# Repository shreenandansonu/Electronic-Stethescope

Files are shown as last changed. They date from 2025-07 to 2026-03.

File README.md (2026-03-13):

    

 

# **EKOBIT** | Electronics Stethoscope

This project aims at making an affordable yet powerful **electronics stethoscope** to **record and listen** to the Heart and Lungs Sound. The stethoscope would be primarily used for teaching purposes for medical students at CMC Vellore, Bagayam Campus, Vellore, Tamil Nadu India. Below mentioned are the objective.

---
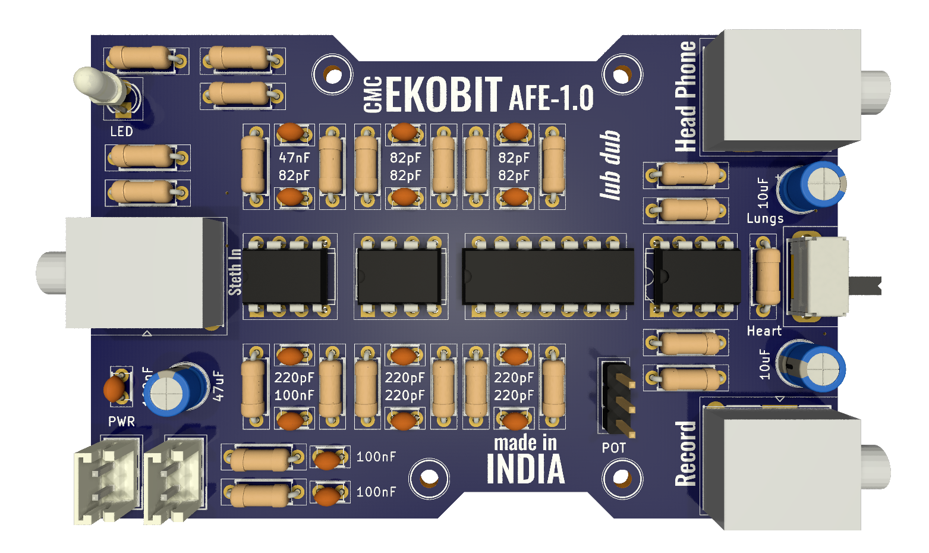
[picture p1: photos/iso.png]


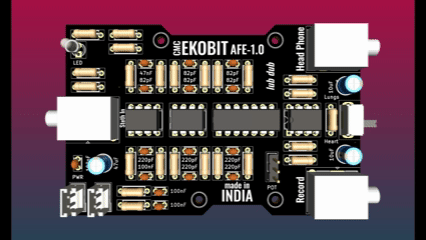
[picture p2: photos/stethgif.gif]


### **OBJECTIVE**
---
| Objectives | Status |
| :---: | :---: |
| Connect stethoscope to a microphone to capture sounds. |  |
| Amplify heart and lung sounds using custom circuits. |   |
| Filter captured sounds using built electronic circuits. |   |
| Transfer audio to PC/mobile via 3.5 mm jack. |   |
| Record and save audio using open-source/custom software. |   |

```
Digitial Version of this device is in progress........
```

## **DEMO**
[EKOBIT DEMO VIDEO](https://youtu.be/8x4jnvdGgfg?si=aJdlGi542GCe0jYr)
---

## **SOFTWARE**
[SOFTWARE DOWNLOAD](https://cmcekobit.netlify.app/)
---

## **DOCUMENTATION**
[DOCUMENTATION DOWNLOAD](https://cmcekobit.netlify.app/EKOBIT.pdf)
---

| Top View | Bottom View |
| :---: | :---: |
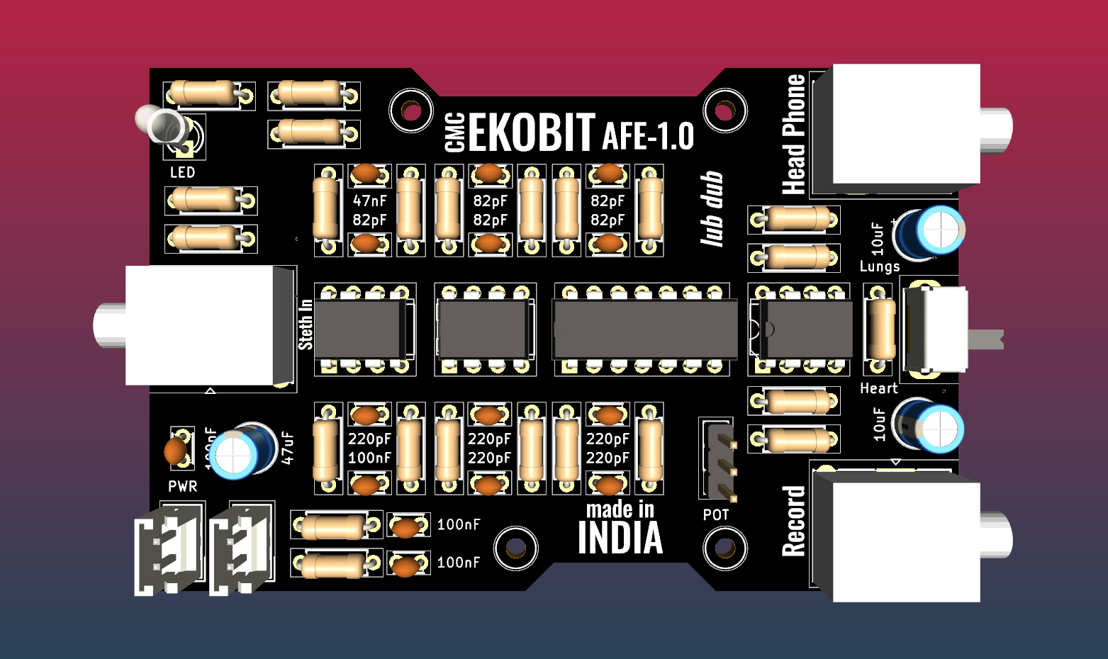
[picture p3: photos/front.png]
Front View
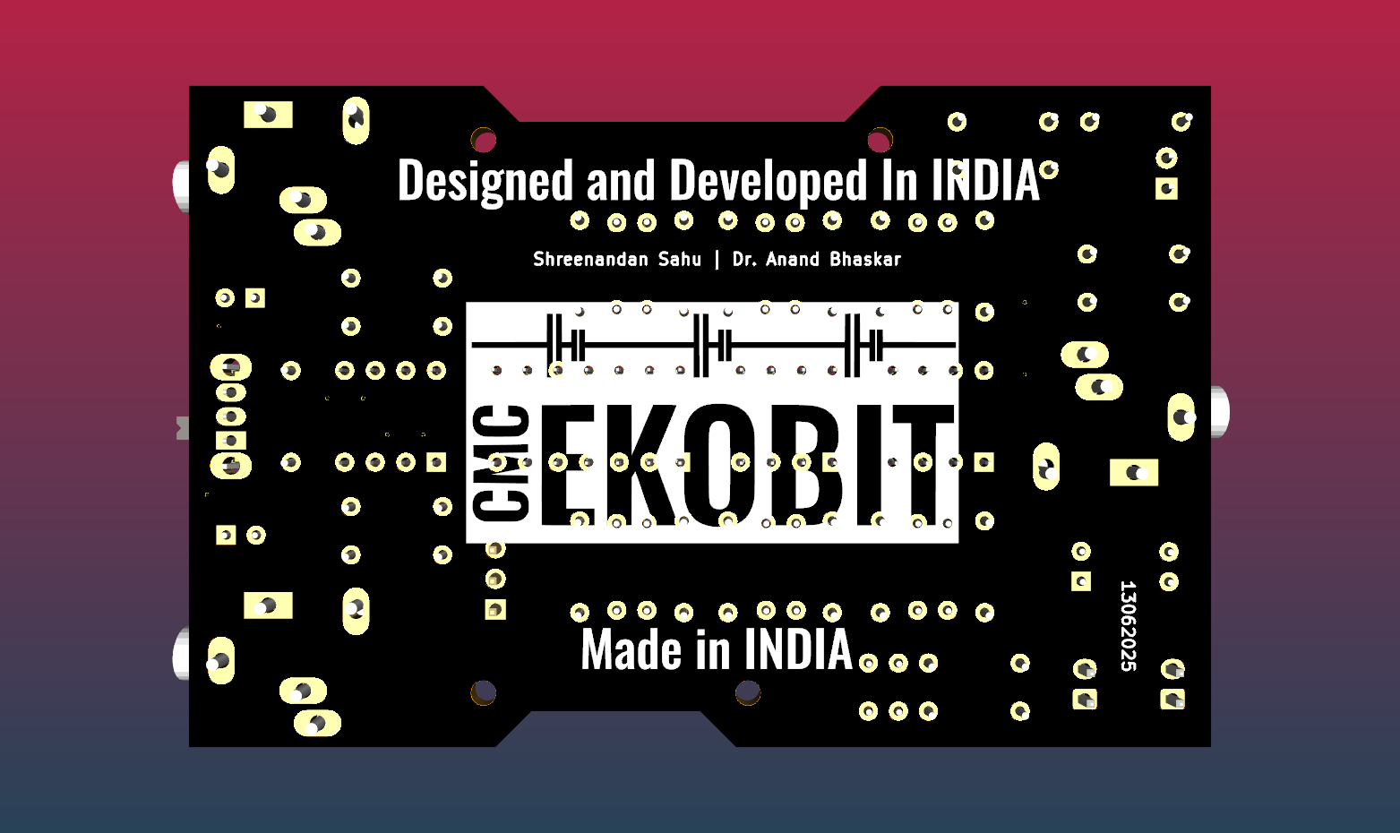
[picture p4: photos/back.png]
Bottom View
|   |   |

---
| PCB Layout | Schematics |
| :---: | :---: |
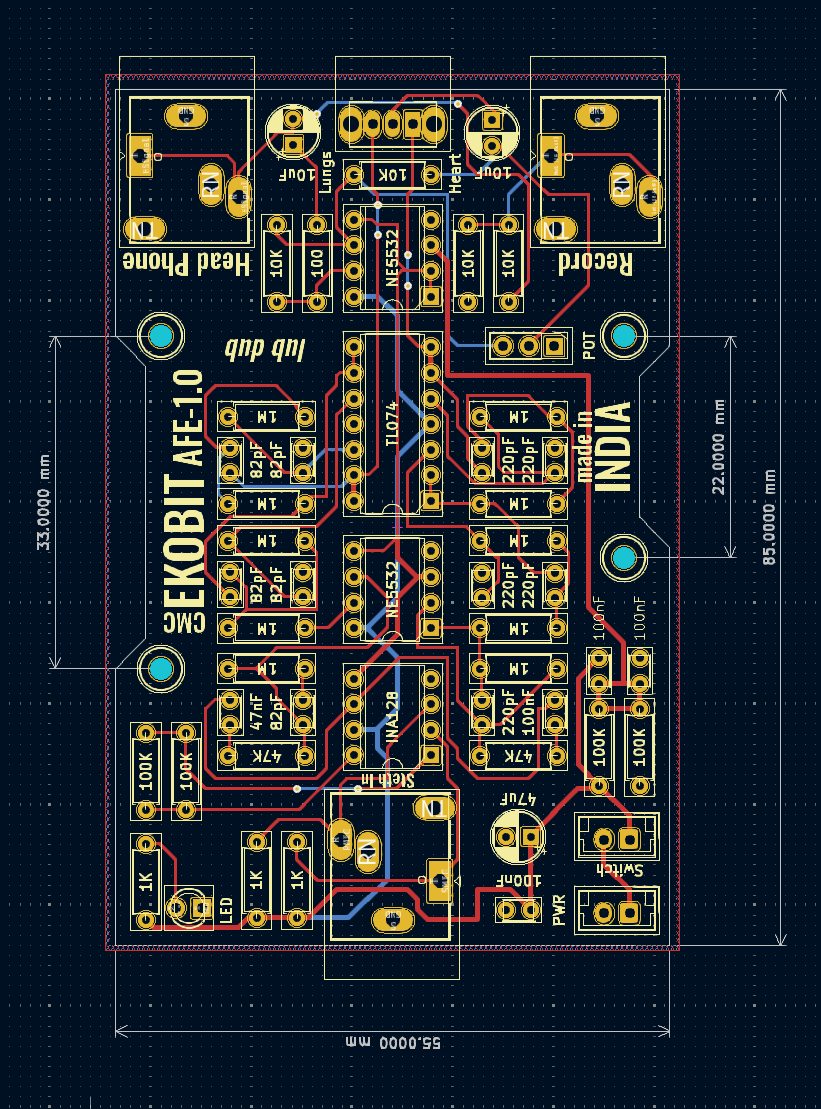
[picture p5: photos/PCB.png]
PCB View
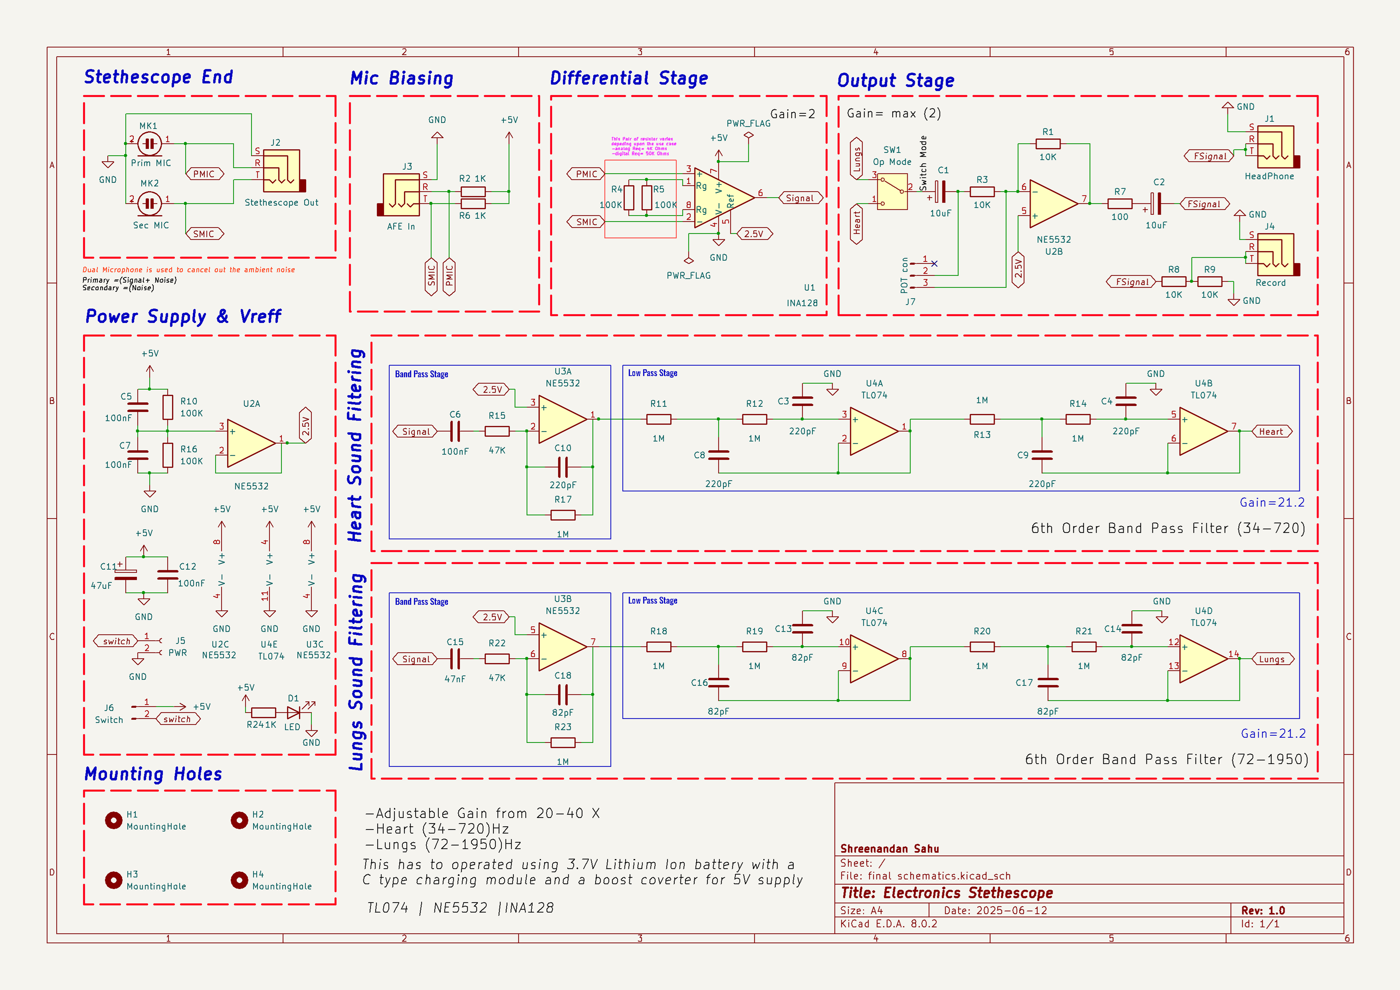
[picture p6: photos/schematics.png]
Schematics
|   |  |

---
| Stethoscope Connector | Stethoscope Enclouser |
| :---: | :---: |
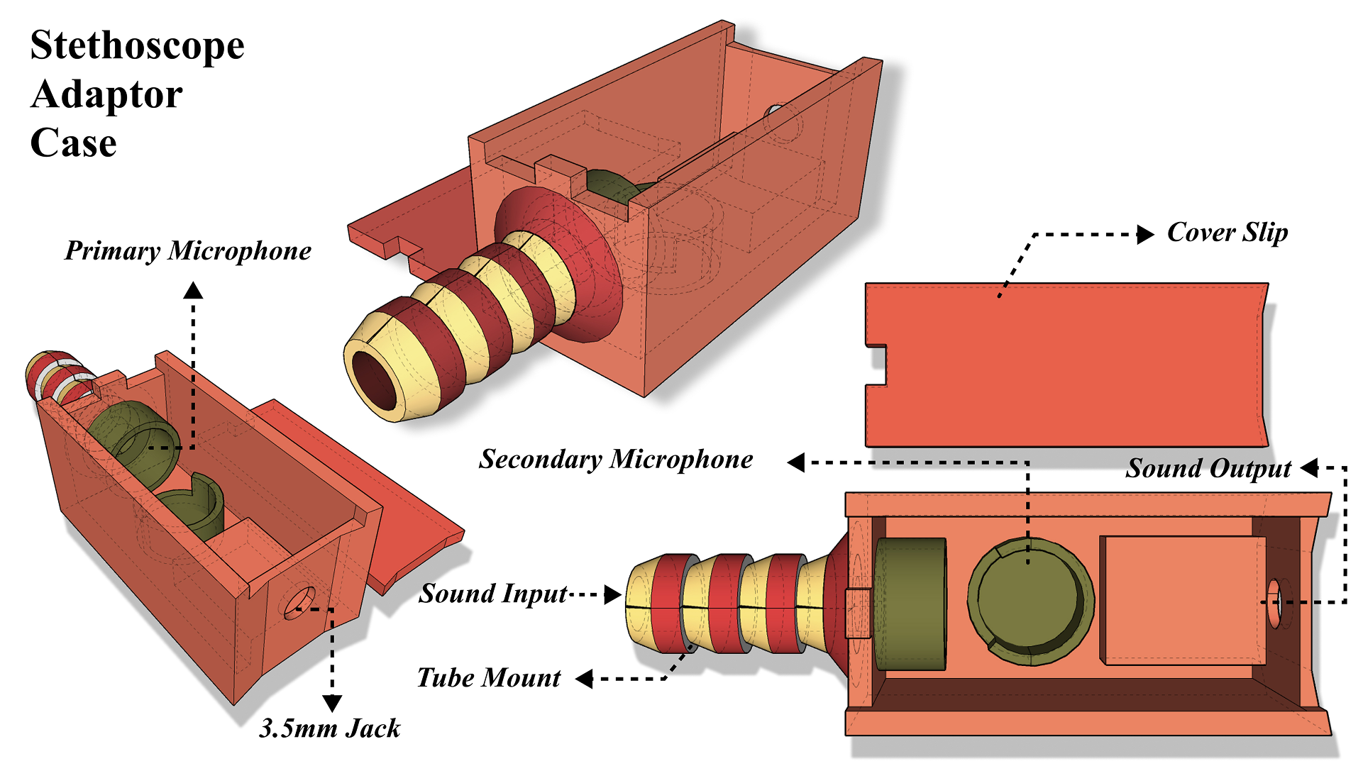
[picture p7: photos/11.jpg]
EKOBIT Stethoconn
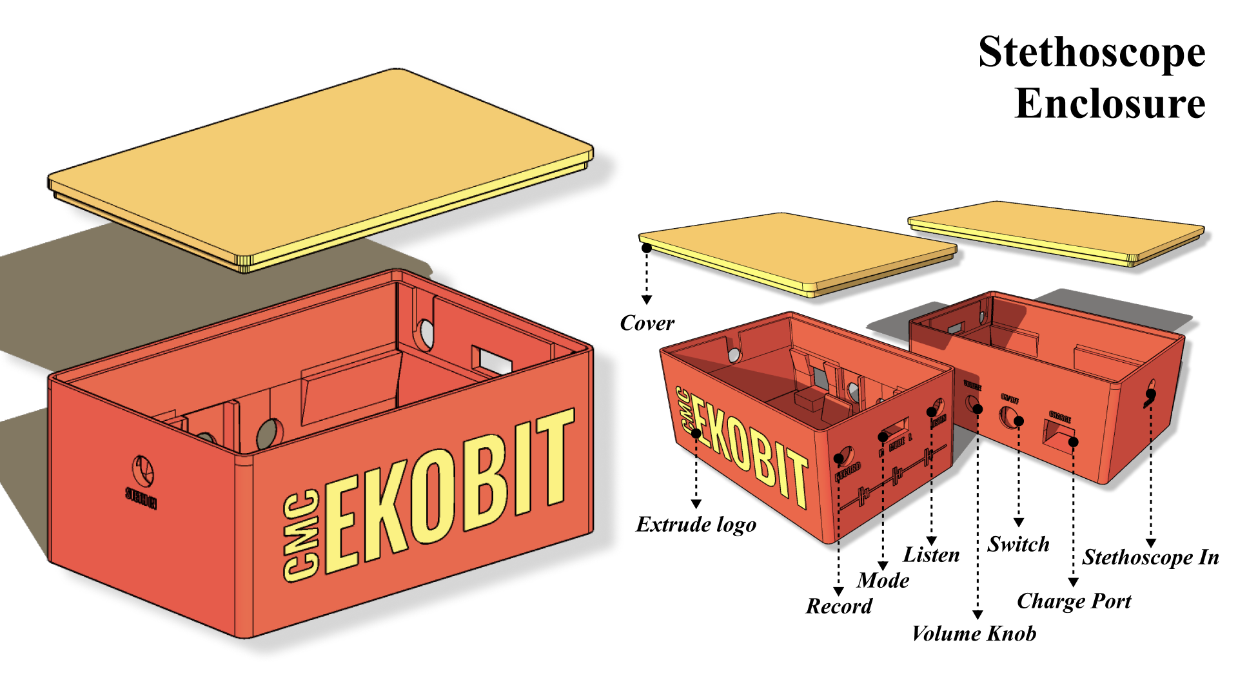
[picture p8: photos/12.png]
EKOBIT enclouser
|   |  |

### **RAW VS PROCESSED** signal DSO

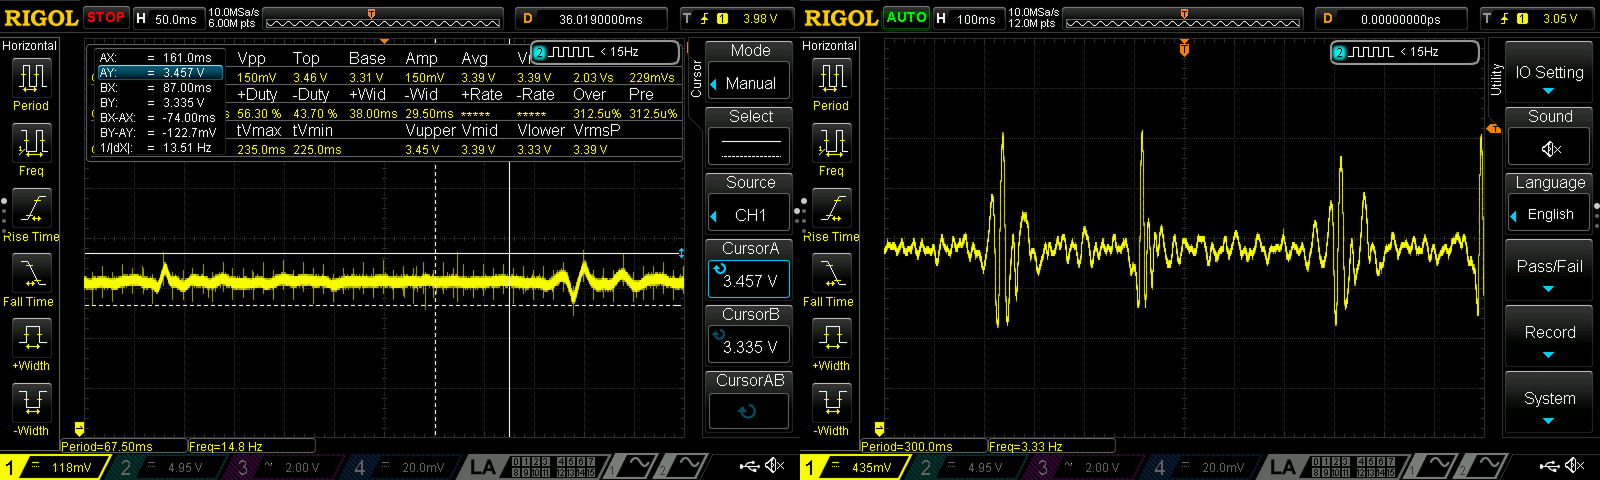
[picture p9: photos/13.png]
DSO Compare


### **RECORDING SOFTWARE**

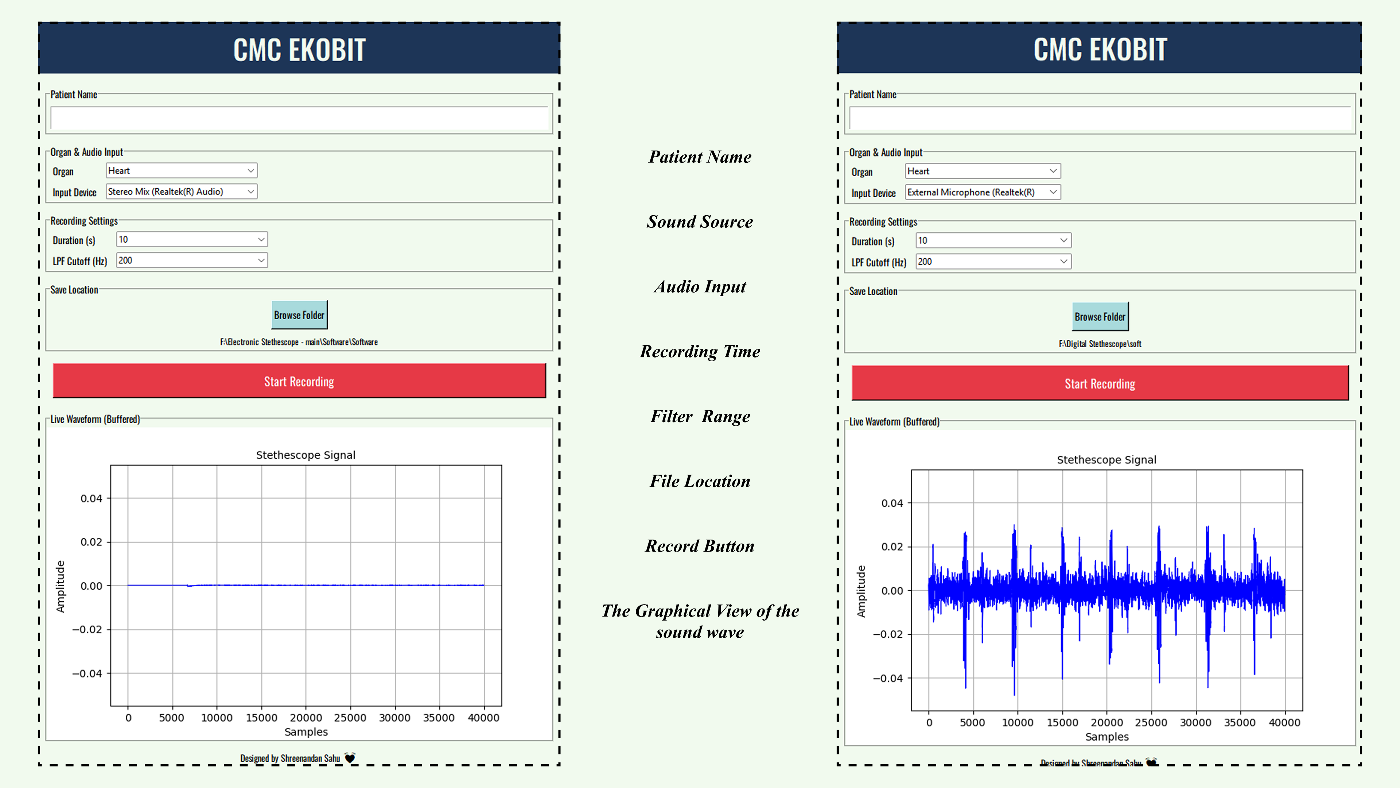
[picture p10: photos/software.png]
Software Anatomy


### **SPECTOGRAM OF RECORDED SOUND**

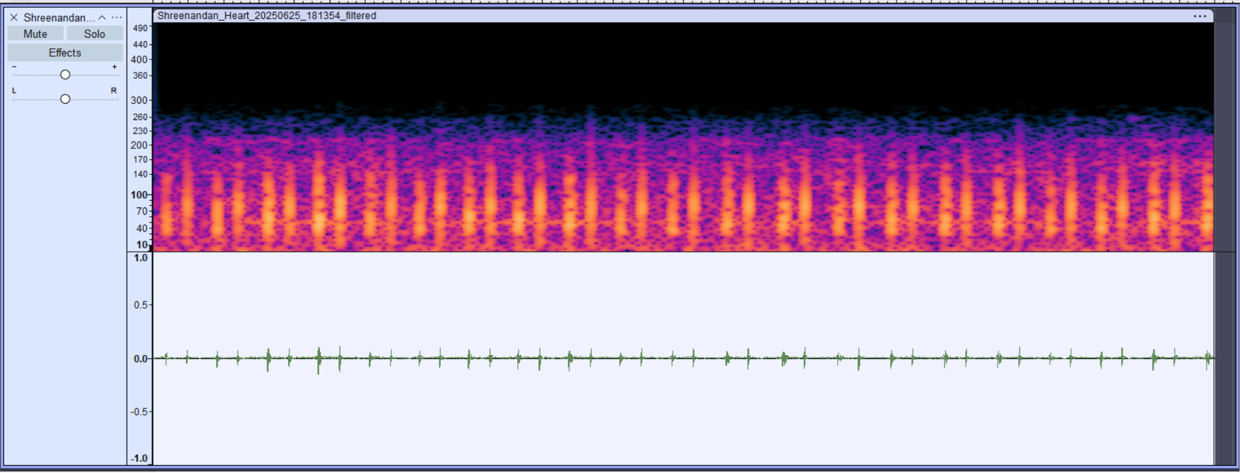
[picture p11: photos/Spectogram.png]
Spectrogram


---
### **FINAL DEVICE DEVELOPED**
| **FINAL PRODUCT** | **HARDWARE** |
| :---: | :---: |
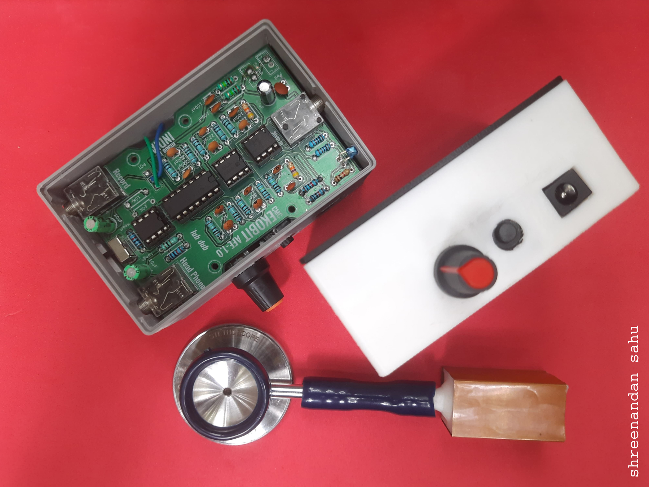
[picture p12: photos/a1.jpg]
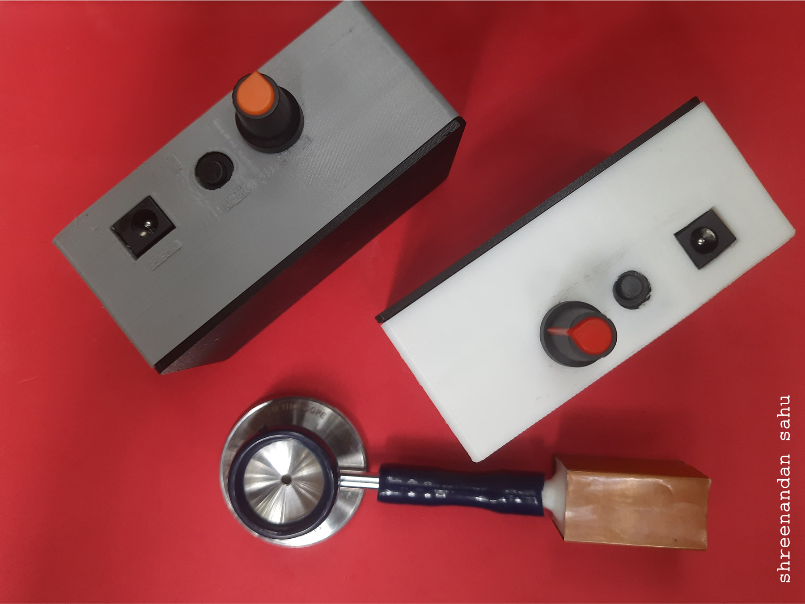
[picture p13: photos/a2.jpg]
| |  |
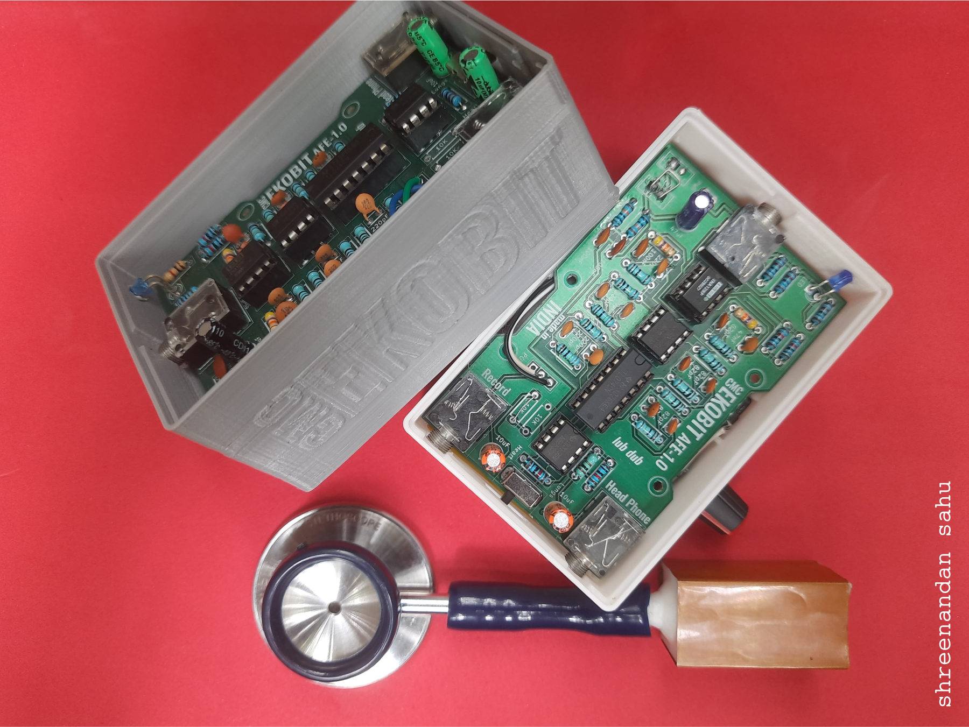
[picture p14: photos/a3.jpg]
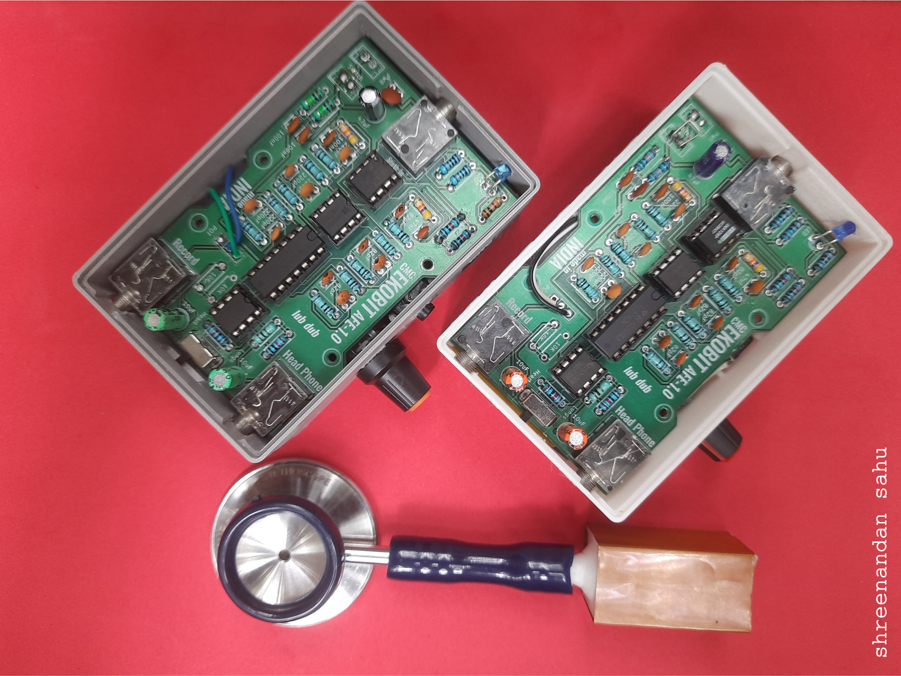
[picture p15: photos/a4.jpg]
| |  |
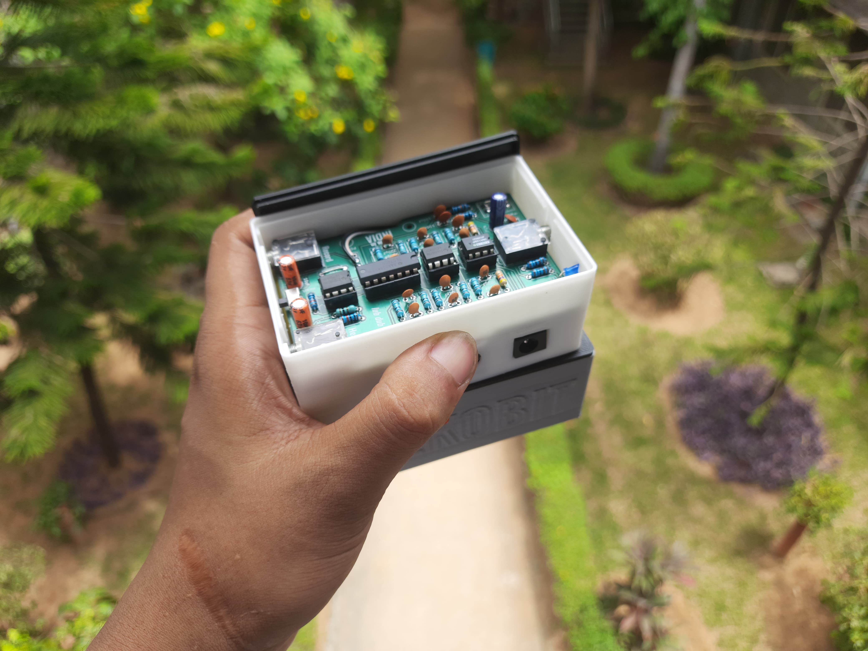
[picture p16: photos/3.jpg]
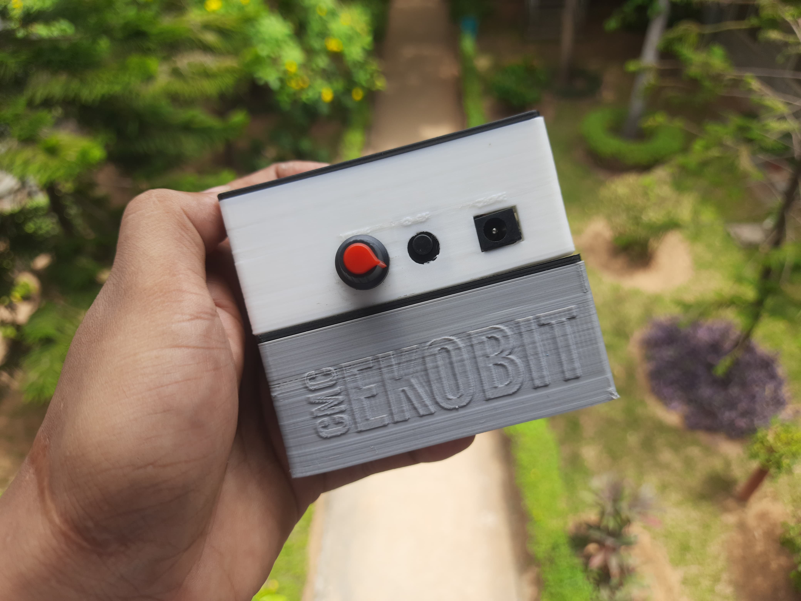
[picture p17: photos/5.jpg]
| |  |
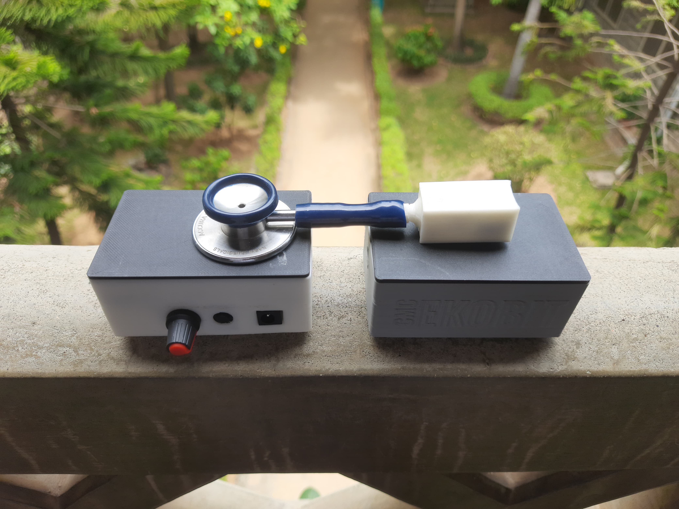
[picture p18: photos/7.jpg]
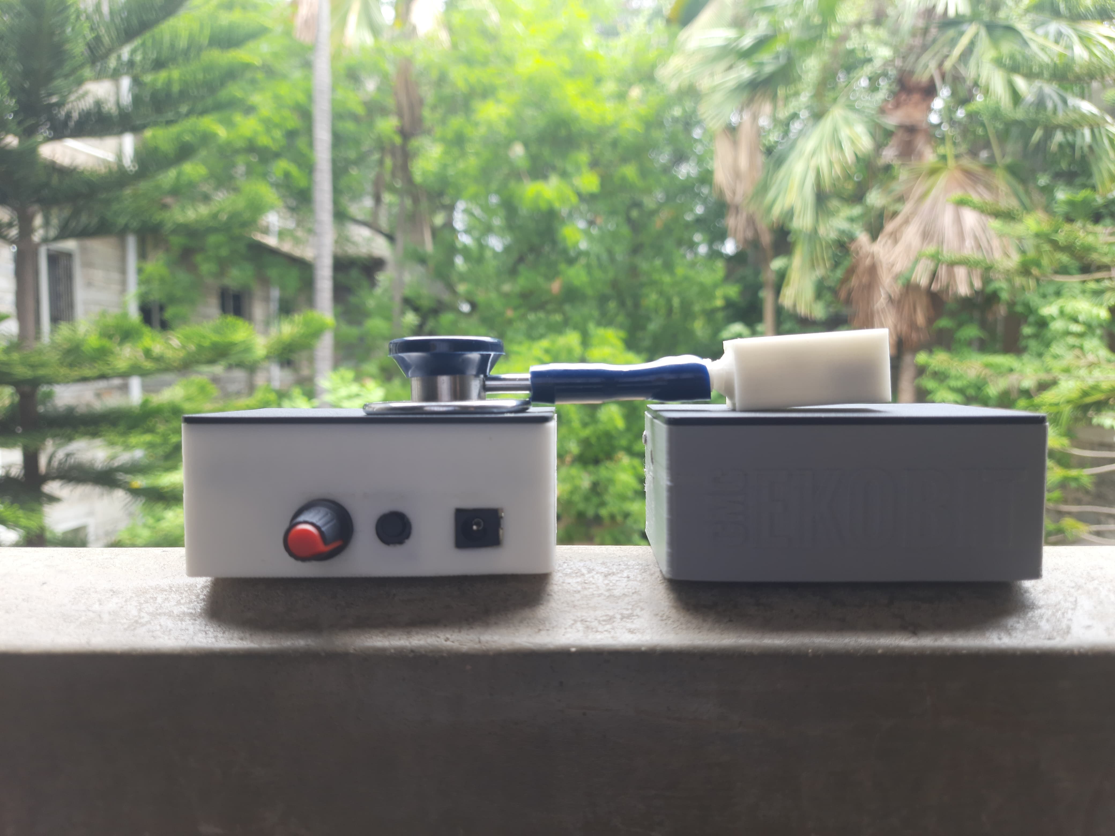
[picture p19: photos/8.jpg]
| |  |

---
### **BEHIND THE DEVELOPMENT**
| **PRODUCT DEVELOPMENT** | **PROTOTYPING** |
| :---: | :---: |
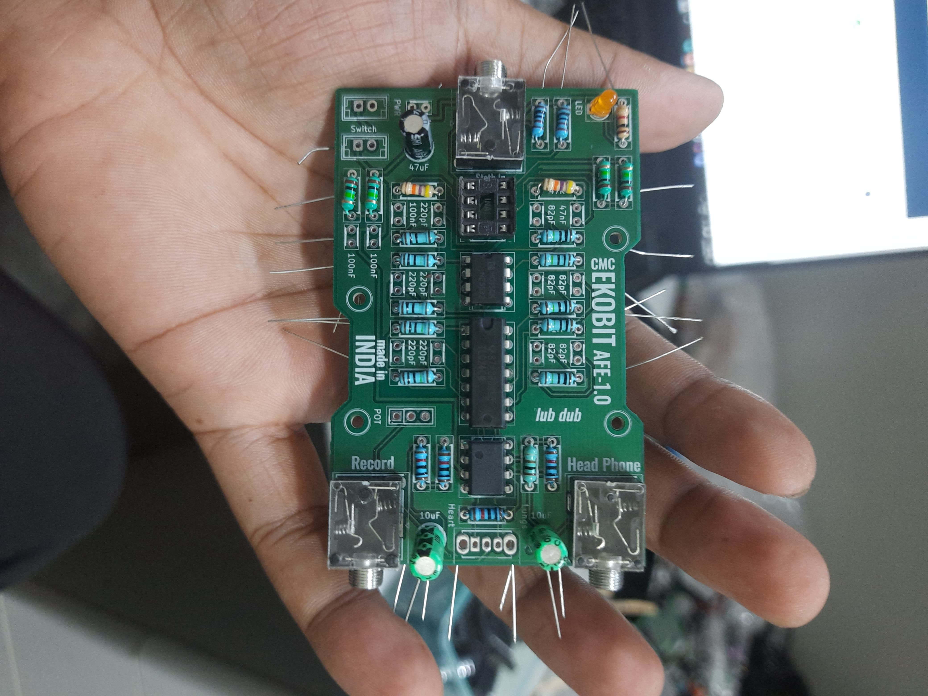
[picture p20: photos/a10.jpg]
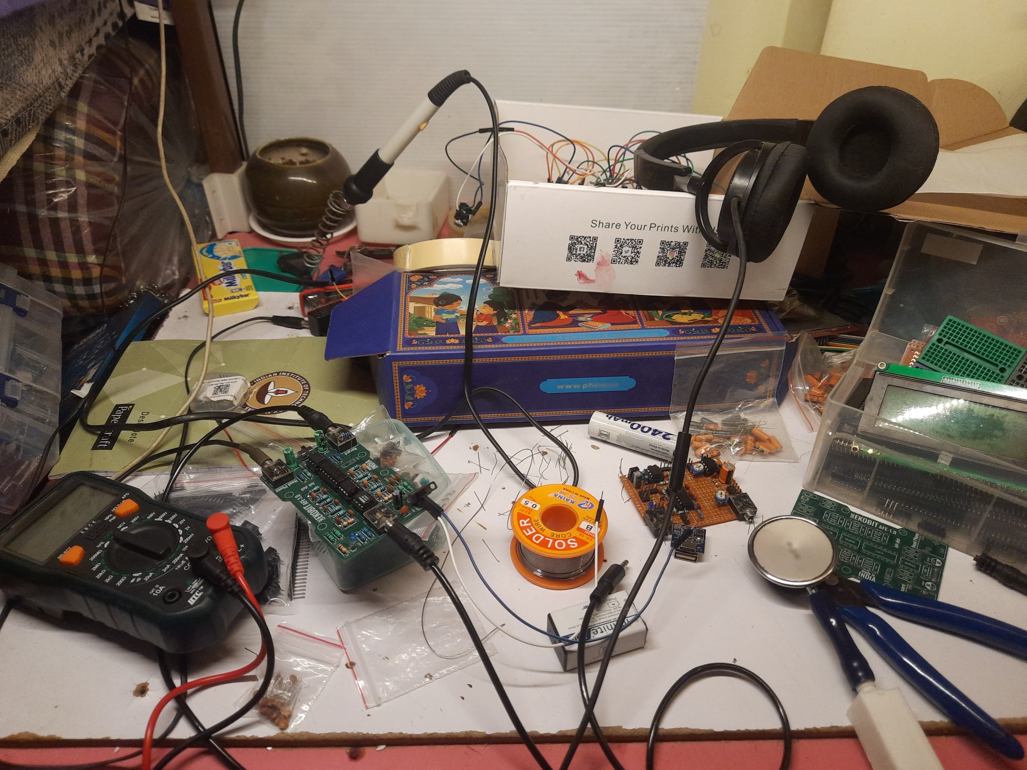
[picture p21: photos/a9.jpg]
| |  |
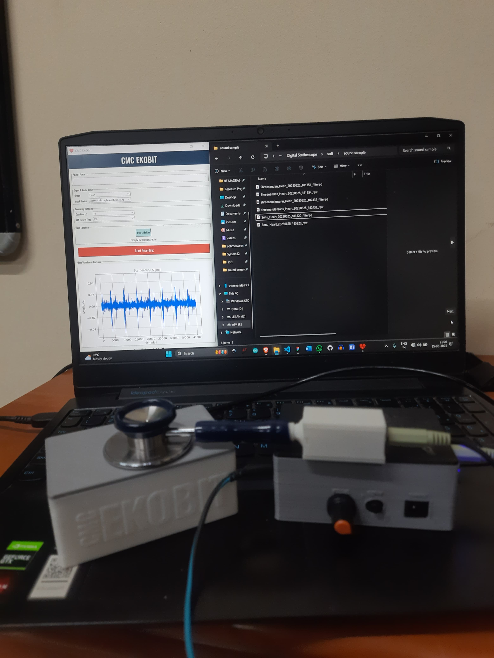
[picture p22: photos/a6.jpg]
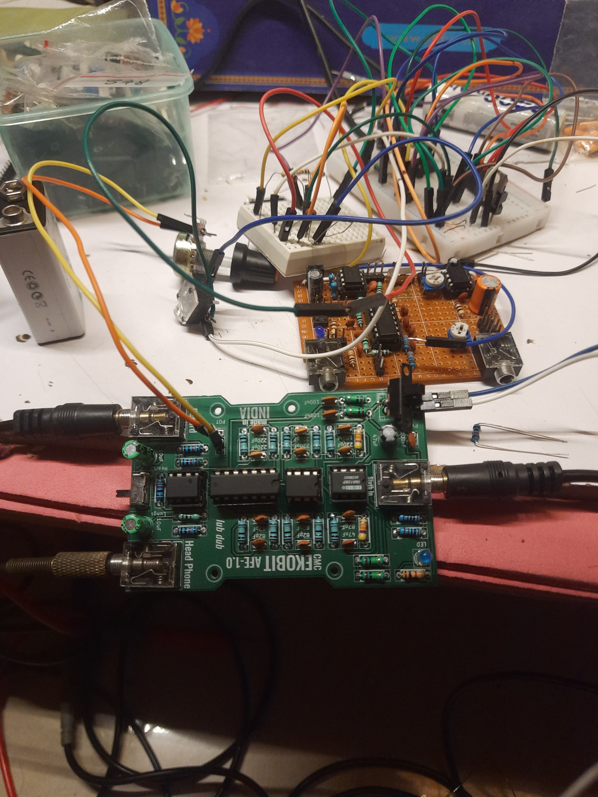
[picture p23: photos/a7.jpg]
| |  |
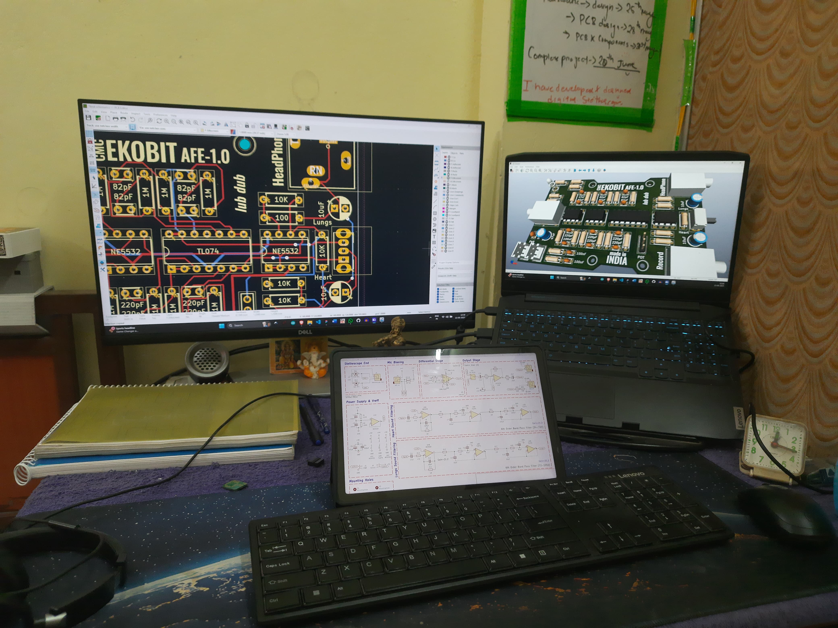
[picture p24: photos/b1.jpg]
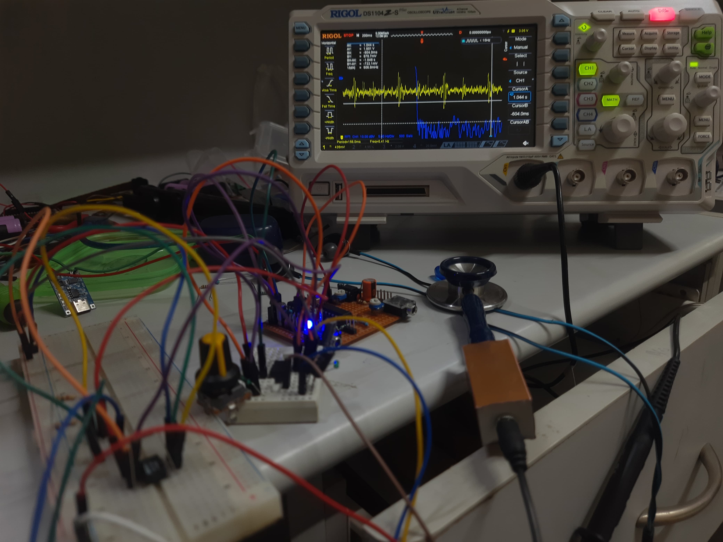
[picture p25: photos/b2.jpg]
| |  |
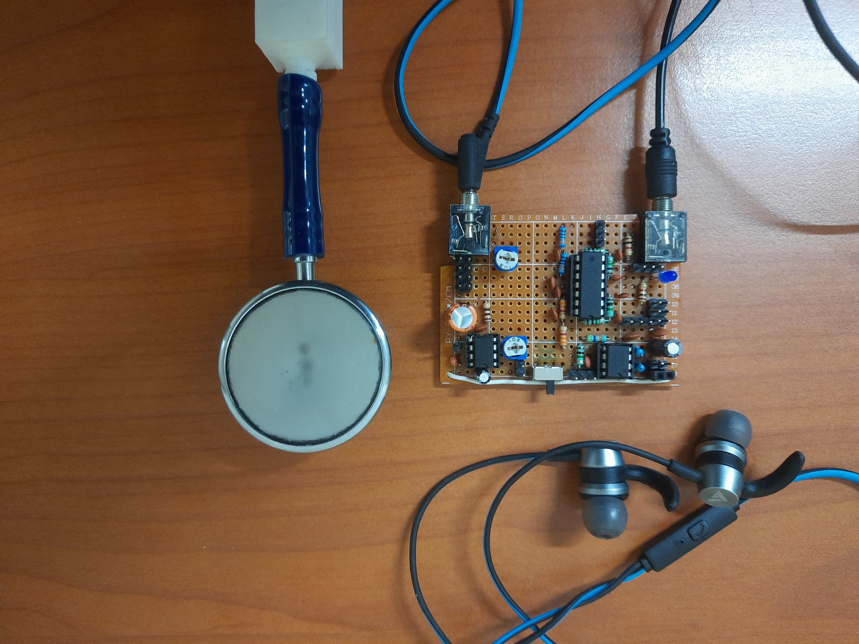
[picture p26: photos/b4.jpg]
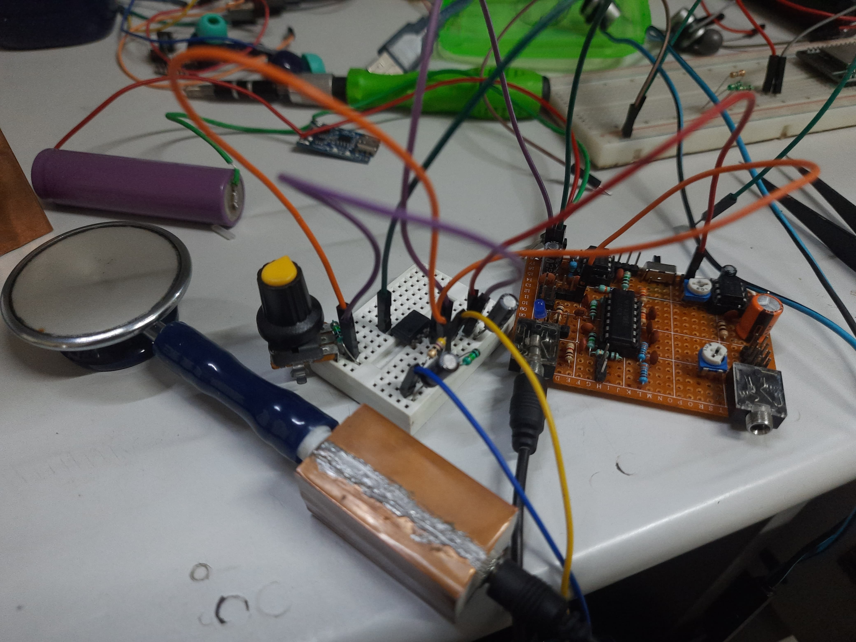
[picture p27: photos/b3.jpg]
| |  |

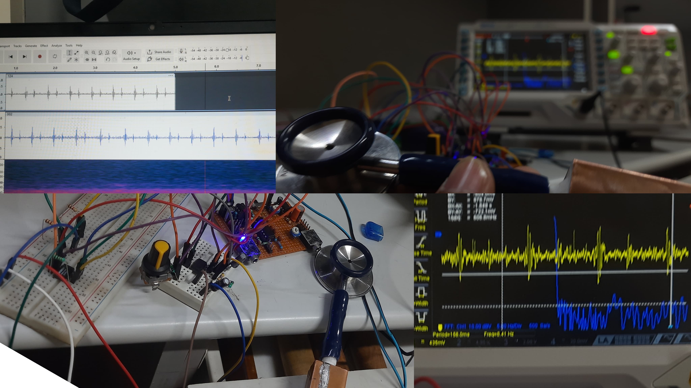
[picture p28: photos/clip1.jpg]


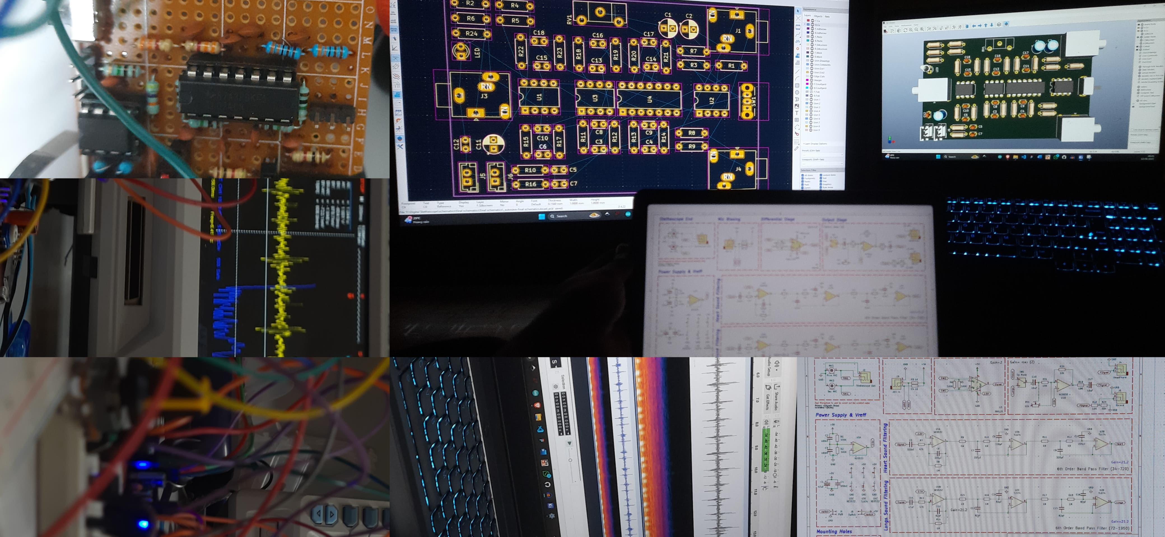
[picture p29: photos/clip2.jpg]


## **SECOND VERSION IN PROGRESS**
|SMD VERSION|
|----|
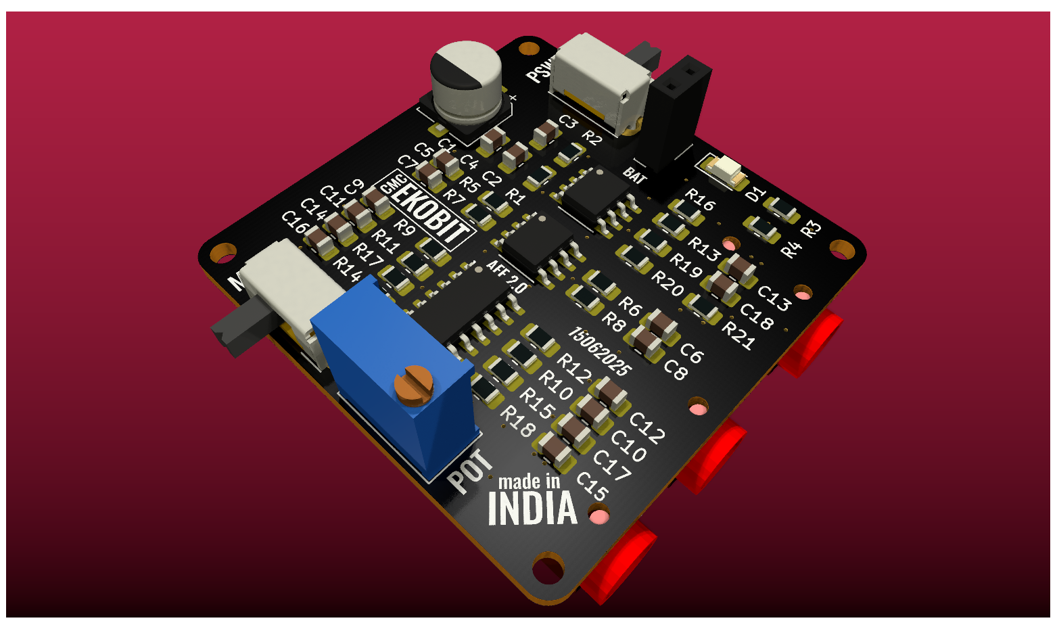
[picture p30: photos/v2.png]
SMD
||

## License

- Software is licensed under the [MIT License](LICENSE).
- Hardware is licensed under the [CERN-OHL-S v2 License](LICENSE-CERN-OHL-S).



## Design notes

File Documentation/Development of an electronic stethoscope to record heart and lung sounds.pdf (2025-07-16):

# Development of an electronic stethoscope to

record heart and lung sounds.

By

# Shreenandan Sahu

## (Roll NO: CL24M013)

## Under the guidance of

## Dr. Anand Bhaskar

## July 2025

## Department of Bioengineering

# Christian Medical College Vellore

## Abstract

This project presents a fully functional electronic stethoscope system developed to

record, filter, and visualize heart and lung sounds using accessible and low-cost components.

A condenser microphone was mechanically interfaced with a traditional stethoscope chest piece

via a custom 3D-printed adapter. The acquired acoustic signals are amplified and passed

through an analog bandpass filter (20–500 Hz or 100-1500 Hz) to isolate physiological sounds

of interest. The output is routed via dual 3.5 mm audio jacks—one for real-time listening and

another for simultaneous recording into a PC or mobile device.

A custom-built Python software interface was developed to capture, digitally filter, and

visualize the recorded sound signals, providing a complete auscultation toolchain. The software

supports real-time waveform plotting, playback, and file storage, making it suitable for both

educational and clinical applications. The final device is compact, portable, and cost-effective,

demonstrating its potential for medical training, telemedicine, and resource-limited healthcare

settings.

Keyword: Electronic Stethoscope, Heart Sounds, Lung Sounds, Bandpass Filter, Signal

Amplification, Python GUI, Biomedical Signal Acquisition

# Contents

Chapter 6: Future Scopes | 17
Chapter 7: Learnings from the project | 18

# Figure List

Figure 1 Stethoscope Adaptor Design (Sketchup) | 9
Figure 2 Schematics of the device (KiCAD) | 10
Figure 3 PCB layout of the device (KiCAD) | 10
Figure 4 Final PCB layout 3D rendered. (KiCAD) | 11
Figure 5 Enclosure of the device Rendered (SKetchUp) | 11
Figure 6 Static and Operation view of the compatible software | 12
Figure 7 The entire PCB after mounting all the components | 13
Figure 8 Developed device with all the components of it | 14
Figure 9 Base Sound VS Amplified sound from the Oscilloscope | 15
Figure 10 Audacity based spectrogram viewer for the recorded sound analysis | 15

# Chapter 1: Introduction

### 1.1. Origin of Stethoscope and the Need for Digital Evolution

Origin of the Stethoscope and the Need The stethoscope, first introduced by René

Laennec in 1816, was designed as a non-invasive tool to listen to internal body sounds,

primarily for assessing the heart, lungs, and airways. Over the decades, it became an

indispensable instrument in physical examinations, helping clinicians diagnose cardiovascular

and respiratory conditions through chest auscultation. Despite its simplicity and effectiveness,

the traditional acoustic stethoscope is limited by its reliance on the clinician’s auditory acuity

and the absence of recording or amplification capabilities.

With the increasing demand for precise, reproducible, and remote diagnostic tools, the

need for digital and electronic stethoscopes has grown significantly. These advanced devices

enable amplification, filtering, and real-time visualization of internal sounds, allowing for

better detection of subtle abnormalities. Moreover, the integration of recording features, data

storage, and connectivity to mobile applications enhances their utility in telemedicine, clinical

training, and longitudinal monitoring. In this evolving healthcare landscape, digital

stethoscopes are not just upgrades—they are essential tools bridging traditional auscultation

with modern diagnostic need for Digital Evolution.

### 1.2. Aim and Objectives

- Captures heart and lung sounds by interfacing a traditional stethoscope chest piece

with a condenser microphone.

- Amplifies the low-level physiological signals using custom-designed analog circuits.
- Filters out background noise using hardware-based bandpass filters to retain only

relevant frequencies.

- Transmits the processed sound to a computer or mobile device through a 3.5 mm

audio jack for real-time listening.

- Records and saves the audio using custom-built or open-source software for further

analysis and documentation.

# Chapter 2: Literature Review

### 2.1. Understanding Stethoscope Parameters

A stethoscope is a fundamental auscultation tool used to detect internal body sounds,

primarily from the heart and lungs. The design and functionality of both traditional and

electronic stethoscopes are based on the acoustic characteristics of these physiological sounds.

Understanding the typical frequency ranges and signal properties of heart and lung sounds is

essential for designing effective electronic stethoscope systems.

Heart sounds typically fall within a low-frequency range of 20 to 150 Hz. The first heart

sound (S1) and second heart sound (S2) are the most prominent and are caused by the closing

of the atrioventricular and semilunar valves, respectively. Abnormal heart sounds such as

murmurs, gallops, or clicks may extend slightly beyond this range but remain in the low-

frequency domain. Due to their low amplitude and frequency, heart sounds require high-gain

amplification and careful filtering to be captured clearly without distortion.

Lung or respiratory sounds, on the other hand, span a broader frequency range, typically

from 100 to 1000 Hz, with some components reaching up to 2000 Hz in pathological conditions

such as wheezing or crackles. Vesicular breath sounds, which are normal lung sounds heard

during inhalation, usually occupy the lower end of this range, while bronchial or adventitious

sounds may be of higher frequency and diagnostic significance.

Electronic stethoscope design must consider these parameters to ensure proper signal

acquisition, amplification, and filtering. Bandpass filters are often set between 20–500 Hz to

cover both heart and the lower range of lung sounds while minimizing environmental noise

and irrelevant high-frequency components. Proper impedance matching, microphone

sensitivity, and gain settings are also crucial to optimize signal clarity and reduce distortion or

loss.

By tailoring these technical parameters to the physiological sound characteristics,

modern electronic stethoscopes can provide clear, accurate audio output, making them useful

not only for real-time diagnosis but also for recording, telemedicine, and machine-learning-

based auscultation support.

### 2.2. Understanding and comparing available devices

Over the past decade, several commercial electronic and digital stethoscopes have

emerged, offering enhanced auscultation features like real-time visualization, sound

amplification, and wireless data transfer. These advancements aim to overcome the limitations

of traditional acoustic stethoscopes, such as low sound clarity, no recording options, and

challenges in remote sharing for teleconsultation and teaching.

The Littmann® Electronic Stethoscope (Model 3200) is a well-known example,

providing up to 24x amplification, Bluetooth connectivity, and PC software integration.

However, with a price of ₹35,000–₹45,000 INR ($400–$550 USD), it is often unaffordable in

low-resource settings. The Eko Core Digital Attachment converts standard stethoscopes into

digital ones, offering features like mobile app visualization and AI-based sound analysis, but

still costs ₹25,000–₹30,000 INR ($300–$360 USD). Wearable systems like StethoMe® and

Clinicloud go a step further with fully wireless monitoring, but also require subscriptions and

typically cost above ₹20,000 INR ($250 USD).

While these devices offer advanced functionality, their high cost, limited accessibility,

and closed-source nature limit their adoption in underserved regions. This creates a clear need

for low-cost, open-source alternatives. Devices that offer basic auscultation functions—like

amplification, filtering, and recording—can be built for as little as ₹1,500–₹2,000 INR ($20–

$25 USD), making them ideal for training and community healthcare.

This project addresses that need, providing a cost-effective, open-design electronic

stethoscope with essential features and a user-friendly software interface for real-world and

educational use.

# Chapter 3: Materials and Methods

### 3.1. Device Fabrication:

3.1.1. Ideation of the device.

The device is designed as an attachable module to a traditional stethoscope chest piece.

It incorporates adaptive noise cancellation using two microphones—one as the primary

microphone for capturing chest sounds and the other as a reference microphone to detect

ambient noise, enabling effective background noise reduction. Both microphones will be

housed within a custom-designed enclosure, which will include proper acoustic sealing and a

nozzle to securely connect the chest piece tubing.

The enclosure will also feature a 3.5 mm audio jack port to connect the device to an

external recording or processing unit. The device will support two operational modes—Heart

Mode and Lung Mode—selectable via a toggle switch, along with a volume adjustment control

for user convenience.

Power will be supplied by two Li-Po batteries, providing up to 7.5V, and the device will

include an integrated charging module. A power switch will control the device, and an LED

indicator will illuminate when the system is powered on.

Upon receiving the input from the microphone assembly, the signal will be processed

through a custom analog circuit designed for amplification and filtering to enhance the relevant

frequency range (20–150 Hz for heart sounds, 100–1000 Hz for lung sounds). The filtered

output will then be routed to two separate 3.5 mm output ports, enabling simultaneous real-

time listening and recording.

This compact, sealed, and user-friendly design ensures ease of use, high-quality signal

acquisition, and adaptability for both clinical and educational applications.

### 3.1.2. Stethoscope Adaptor Design

Our aim is to make an adaptor to house 2 microphone and 3.5mm jack, apart from that

it has a nozzle to conduct the sound from chest piece to the mics. The mics must place close to

each other to capture the unwanted sounds equally so that it can be eliminated. The adaptor

needs to be small but efficient. It should not conduct the movement sounds.

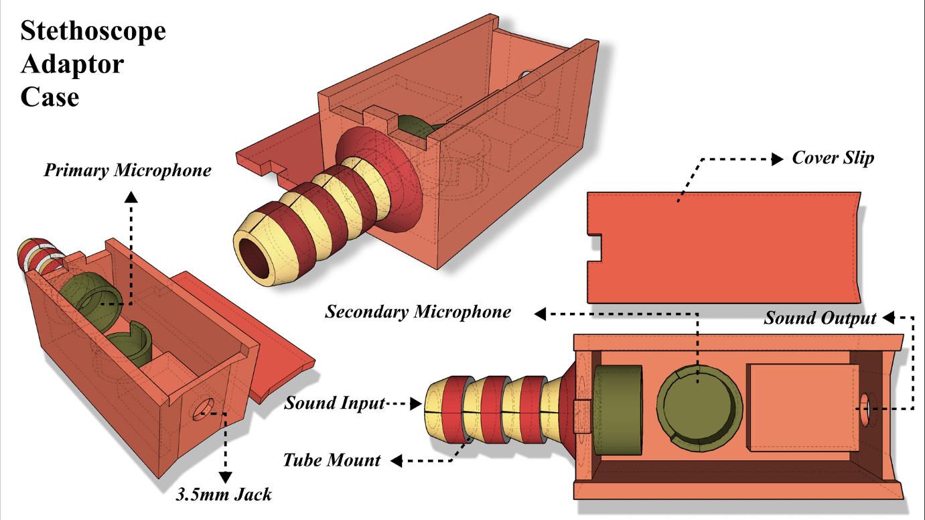
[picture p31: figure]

Figure 1 Stethoscope Adaptor Design (Sketchup)

### 3.1.3. Stethoscope Circuit Design

The main backbone of the electronics circuit is the op-amp and the instrumentation

amplifier which amplifies and filters out the signal. The main obstacle faced was to operate

these op-amp in single power supply. After going though application reports form

manufactures, we ended up with some configuration which has been implemented in the AFE board. We have gone with 6th order filters to clearly filter the upper frequencies. For the op-

amps to properly run by a single supply we have used virtual ground with value equivalent to

Vcc/2. This makes the amplification suitable and non-saturating as the waves are sinusoidal.

Instrumentation amplifier was used at the first stage to get differential output from the

2 mics with adaptive noise cancellation by using pression resistance. Once it was done it then passed through a 1st order high pass filter then it went through 5

th order low pass filter. This

cleaned and simultaneously amplified the signal to about 20 to 40 times the input signal. The

user had an option to choose between the lung and heart sound via a toggle switch. Then the

sound via a power amplifier goes to the 3.5mm jack for listening and recording.

A total of 6 op-amps are use and 1 INA is used to process the signal in the analog front

end. The mics are electret mics which are biased via 1K ohm resistance. One of the opamp is

used for half Vcc generation. Before the power supply is fed to the board its filtered. Overall,

from start to end the stethoscope has total amplification of 80-100 times the input.

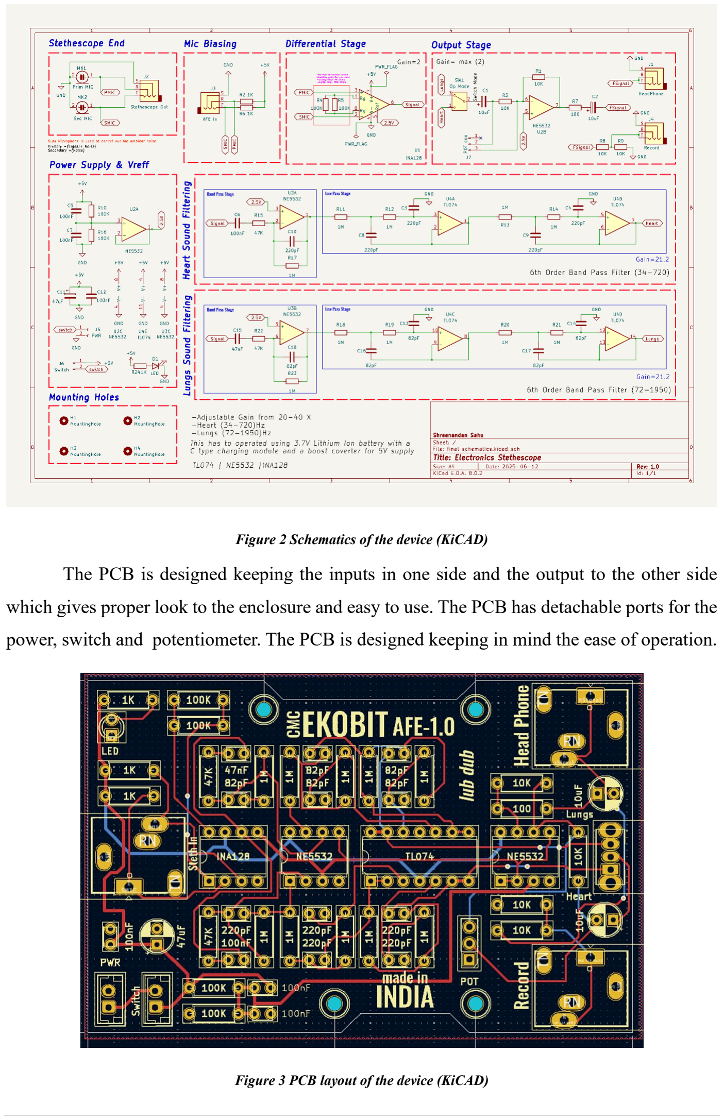
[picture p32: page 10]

Figure 2 Schematics of the device (KiCAD)

The PCB is designed keeping the inputs in one side and the output to the other side

which gives proper look to the enclosure and easy to use. The PCB has detachable ports for the

power, switch and potentiometer. The PCB is designed keeping in mind the ease of operation.

Figure 3 PCB layout of the device (KiCAD)

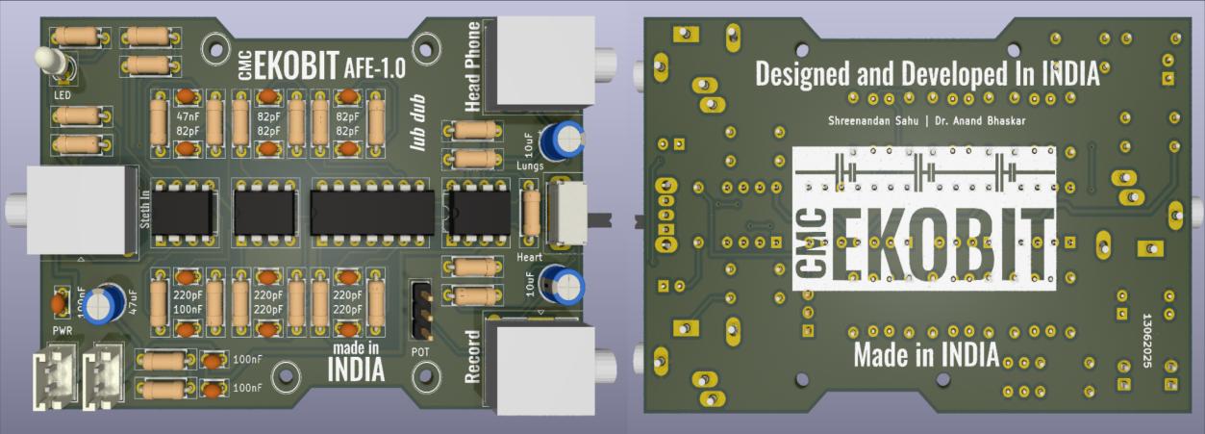
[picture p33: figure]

Figure 4 Final PCB layout 3D rendered. (KiCAD)

### 3.1.4. Stethoscope Circuit Enclouse Design

The enclosure will house the entire circuit along with the accessories like the power

switch, charging port, batteries, charging module, potentiometer, and the indicator LED. These

components are stacked into 2 layers, bottom will have all the batteries and its peripheral along

with the potentiometer on one side. The box size is mainly decided by the PCB. To mount the

PCB we have designed edges to keep the PCB firmly on. For the inputs and output all the

desired ports were made. Logo of the product was also engraved to one side and other parts

were properly marked out. On top of everything we have a cover slip to enclose all once all the

connections and parts are properly placed into the box.

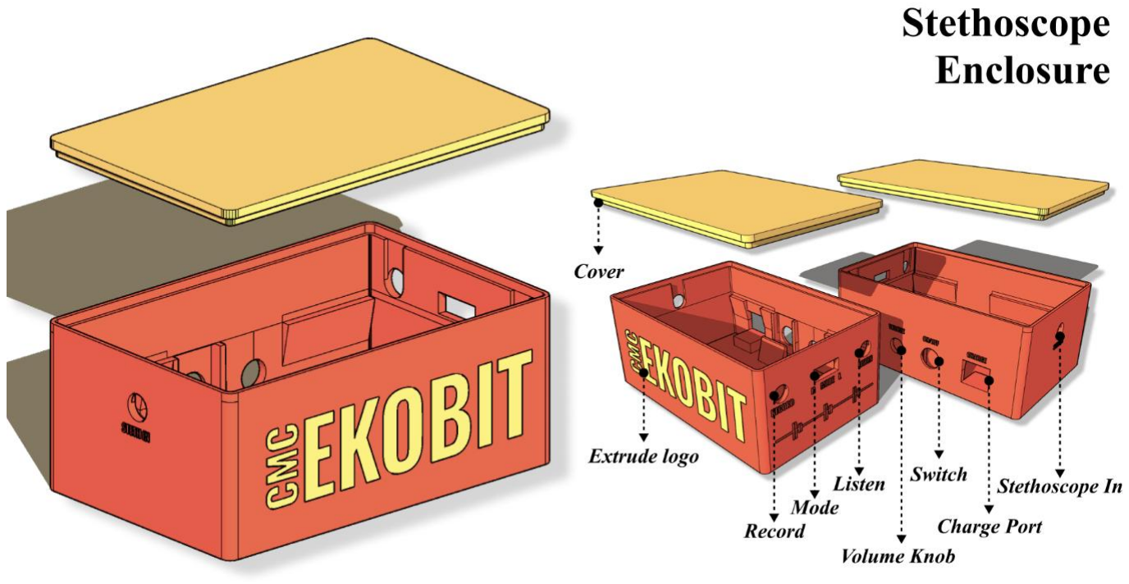
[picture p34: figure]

Figure 5 Enclosure of the device Rendered (SKetchUp)

### 3.1.5. Stethoscope Recording Software

The heart and lung sound can be directly heard via the output using earphone but for

the recording purpose we need to have some software interface. Although it can be directly

recorded using 3.5 mm jack and any recording software and any device e.g., Mobile phones,

Computers etc, but for best results and digital filtering we have built our own compatible

software. The software allows us to record the sounds at 8KHz sampling frequency and has

digital filter like notch filter at 50 Hz.

The software was written in Python and using libraries of python. It has basic and clean

interface which allows us to use it smoothly. It has field for patient details, organ to be

auscultated, filtering range and record time. It has file saving location option also. Visually it

has the waveform viewer which shows the live unfiltered view of the sound input.

Once all the parameters are set and the software starts recording, it records for the

duration and the saves it in the location and gives a confirmation pop up. It stores both the

RAW and the filtered sounds in the same file location. Software can record with different

parameter set by the user.

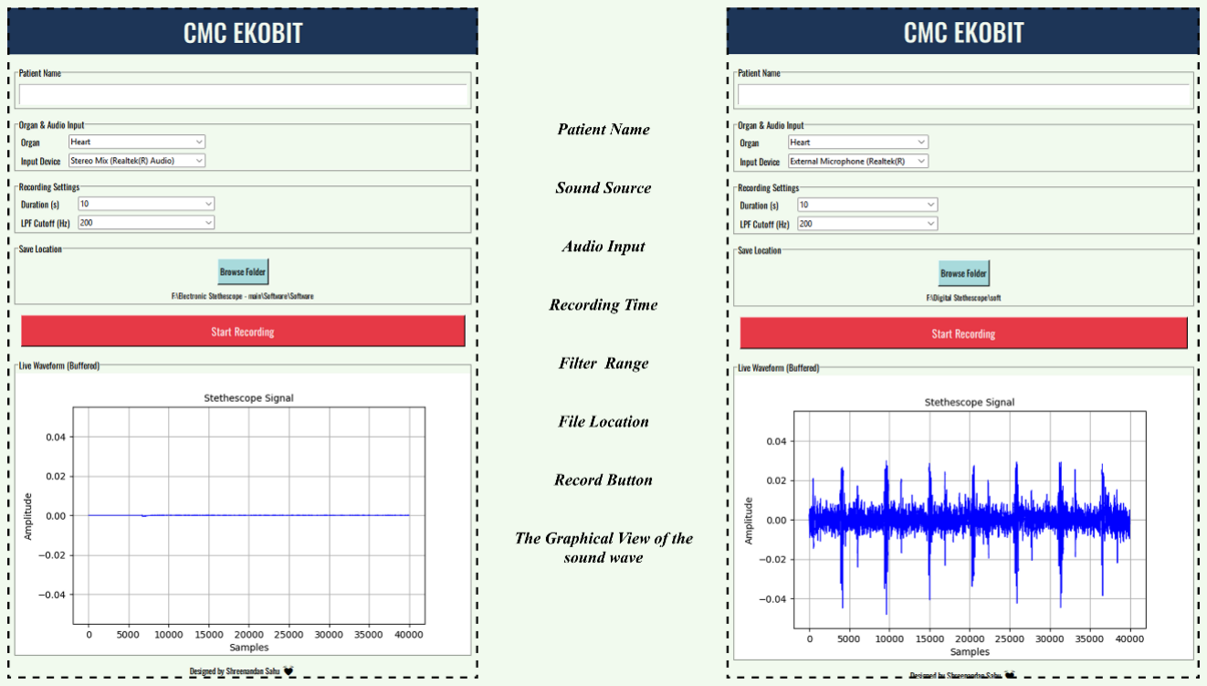
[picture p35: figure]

Figure 6 Static and Operation view of the compatible software

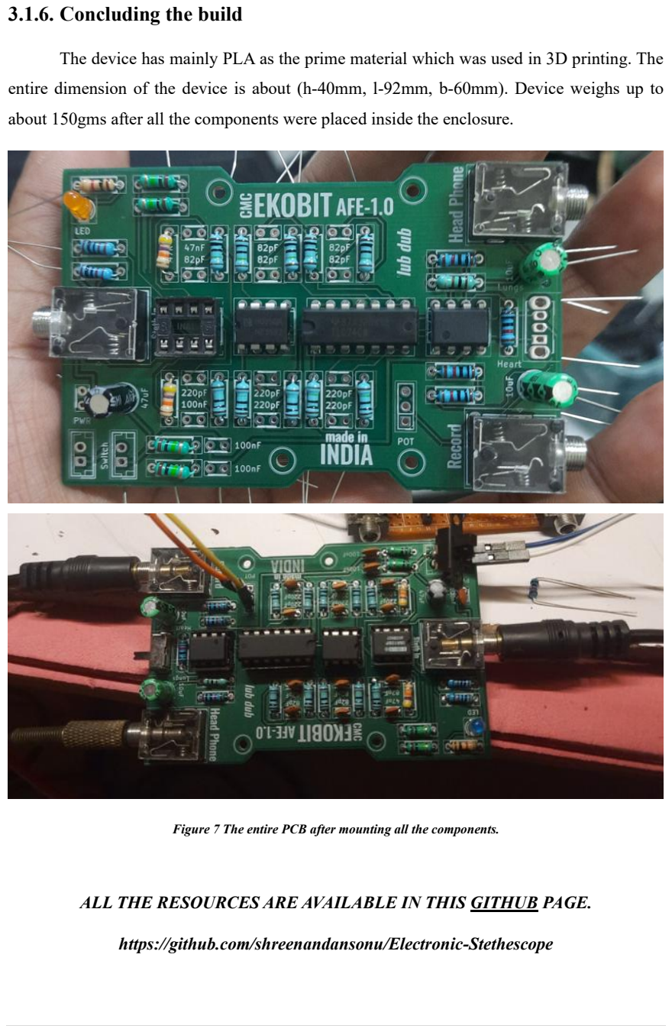
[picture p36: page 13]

### 3.1.6. Concluding the build

The device has mainly PLA as the prime material which was used in 3D printing. The

entire dimension of the device is about (h-40mm, l-92mm, b-60mm). Device weighs up to

about 150gms after all the components were placed inside the enclosure.

Figure 7 The entire PCB after mounting all the components.

ALL THE RESOURCES ARE AVAILABLE IN THIS GITHUB (https://github.com/shreenandansonu/Electronic-Stethescope) PAGE.

https://github.com/shreenandansonu/Electronic-Stethescope

# Chapter 4: Results and Discussion

### 4.1. Final assembled device:

The device was successfully developed and designed. Proper offset was maintained for

the proper fitting of the PCB into the enclosure. The Enclosure was built using 3D printer (Flash

Forge) using PLA material of black and grey color. The adaptor must be placed inside a metallic

plating to avoid the unwanted noises.

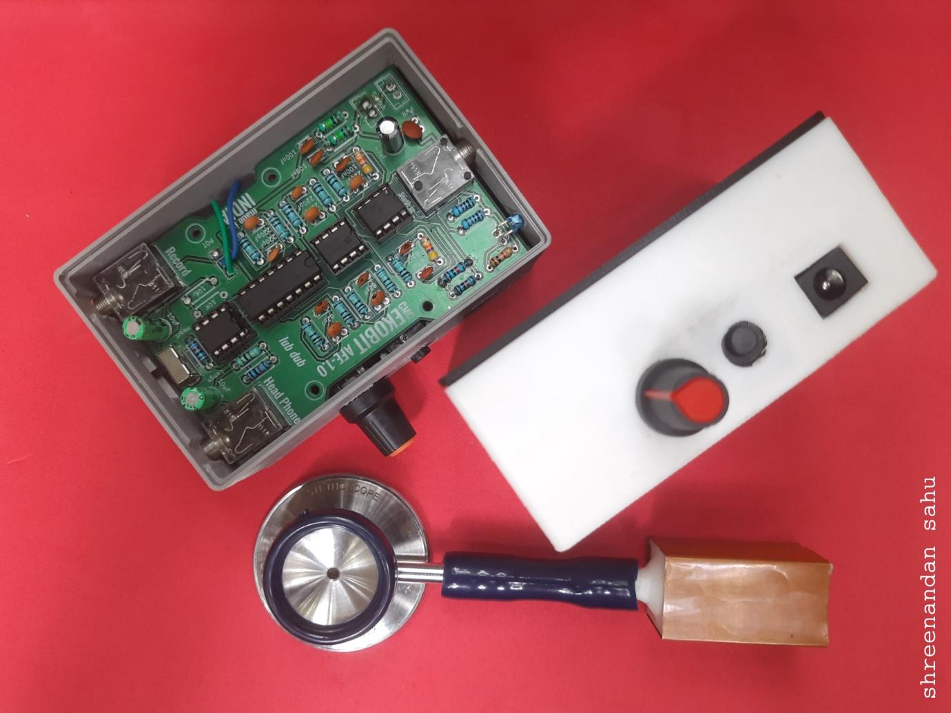
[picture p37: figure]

Figure 8 Developed device with all the components of it.

### 4.2. Testing of the Device:

4.2.1. Oscilloscope Based Amplification Testing.

We have tested the device successfully using digital oscilloscope (Rigol DS1104). First,

we tested the bare mic without amplification. That gave us results with our signal in the range

of 120mV peak to peak. After the PCB was completely build, we tested it in the DSO, and it

gave us acceptable signal range of around 1740mV. That shows that the device amplified the

signal properly without distortion (with adjusted volume).

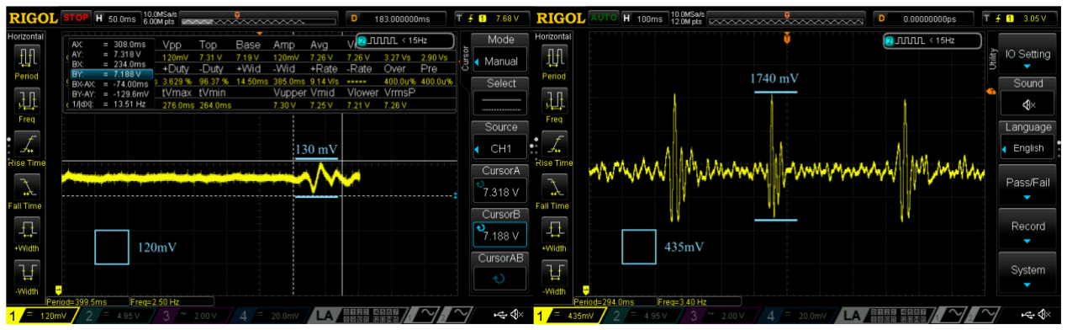
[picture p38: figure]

Figure 9 Base Sound VS Amplified sound from the Oscilloscope
4.2.2. Recorded Sound based Frequency Testing.

We have tested the recorded sound from device successfully using digital sound

recorder (Audacity. We visualised the recorded sound using spectrogram and the results were

acceptable. The main band of the spectrogram lied below the 500Hz band and once filtered it

lied below the 200Hz band.

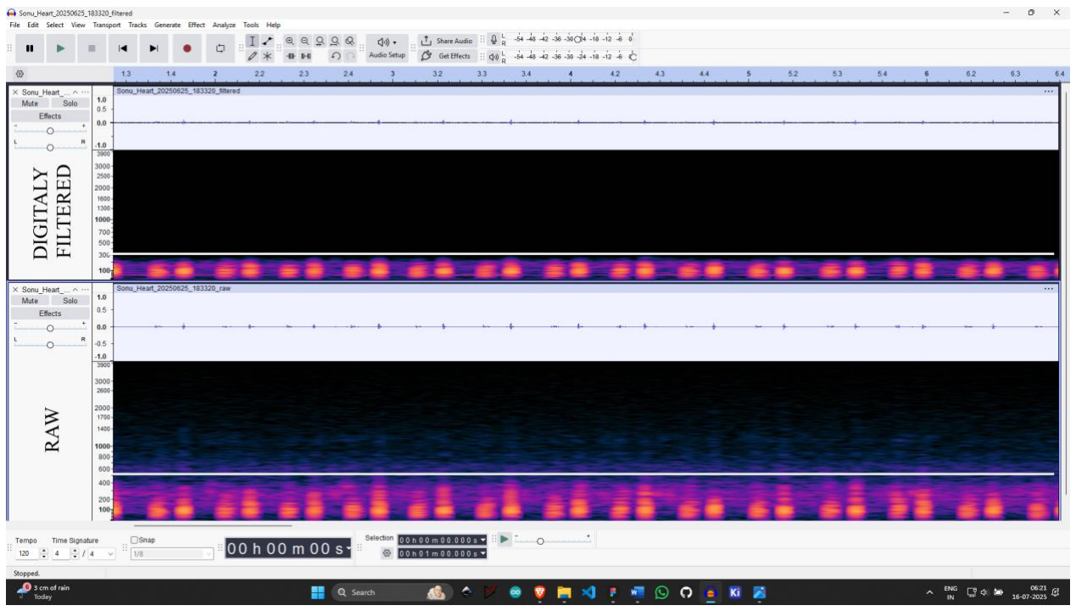
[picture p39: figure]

Figure 10 Audacity based spectrogram viewer for the recorded sound analysis.

The final device was successfully developed, assembled, and tested, meeting the

desired performance criteria. Overall, the developed system proved to be functional, reliable,

and ready for further application-specific deployment.

# Chapter 5: Conclusion

### 5.1 Summery:

Design and Development:

- A low-cost electronic stethoscope was designed for heart and lung sound monitoring,

offering amplification, filtering, and recording features.

- A thorough literature review was conducted on stethoscope frequency parameters and

market options, focusing on the need for accessible diagnostic tools.

- Device fabrication involved custom-designed analog circuits, adaptive noise

cancellation using dual microphones, and a 3D-printed enclosure tailored for optimal

acoustic performance.

- A dedicated Python-based software was developed for real-time sound visualization,

recording, and basic digital filtering, with a user-friendly interface.

Validation and Testing:

- Hardware testing was conducted using a digital oscilloscope (Rigol DS1104),

confirming significant signal amplification from 120 mV to approximately 1740 mV

without distortion.

- Sound recording analysis via Audacity and spectrogram visualization confirmed proper

capture of relevant frequencies, mainly below 500 Hz, with effective background noise

reduction.

- The final assembled device demonstrated clear, amplified physiological sounds with

dual-mode operation for heart and lung auscultation.

### 5.2 Conclusion:

We successfully designed, developed, and validated an affordable electronic stethoscope

capable of amplifying, filtering, and recording heart and lung sounds. The device combined

efficient hardware design, 3D-printed enclosures, and custom software to deliver a reliable

point-of-care diagnostic tool. Testing with oscilloscopes and audio analysis confirmed the

device's ability to capture clean and clear physiological sounds, making it suitable for clinical

training, telemedicine applications, and potential integration with AI-based diagnostic systems.

# Chapter 6: Future Scopes

The developed electronic stethoscope serves as a foundation for further enhancements to

make it more versatile and clinically applicable. Future improvements can include:

- Wireless Data Transmission: Integration of Bluetooth or Wi-Fi modules to enable

wireless audio streaming and remote monitoring via mobile applications or

telemedicine platforms, eliminating the need for physical connections.

- Digital Signal Processing (DSP): On-board microcontroller-based DSP can be

incorporated to perform real-time noise cancellation, adaptive filtering, and sound

classification before transmission.

- AI-Powered Diagnostics: Development of machine learning algorithms for automatic

detection of abnormal heart or lung sounds to assist in preliminary screenings and

reduce diagnostic errors.

- Multi-Organ Mode Expansion: Expansion of the device to include additional

auscultation modes, such as bowel or vascular sounds, broadening its clinical utility.

- Rechargeable and Compact Design: Further miniaturization and integration of

rechargeable power sources with improved battery life to make the device more

portable and user-friendly.

These advancements would enhance the practicality of the device, making it a more

comprehensive, smart, and connected healthcare tool.

# Chapter 7: Learnings from the project

Understanding of Biomedical Devices: Gained in-depth knowledge of stethoscope design,

human auscultation sounds, and the clinical importance of heart and lung sound monitoring.

Literature Review Skills: Learned how to systematically research and review existing

devices, their features, limitations, and cost factors to identify gaps and design goals.

Analog Circuit Design: Developed hands-on skills in designing and implementing analog

circuits using op-amps, instrumentation amplifiers, filters, and power management systems.

PCB Designing and Fabrication: Acquired practical experience in designing PCB layouts

using KiCad, understanding component placement, routing, and preparing files for

manufacturing.

3D Modelling and Printing: Gained proficiency in designing mechanical enclosures using

software like SketchUp and fabricating them using 3D printing techniques.

Software Development: Learned to develop basic software in Python for data acquisition,

real-time plotting, filtering, and storing physiological sounds with a user-friendly interface.

Testing and Validation Methods: Understood the process of validating medical devices

through oscilloscope testing, sound spectrogram analysis, and performance benchmarking.

Project Planning and Execution: Improved project management skills, from ideation to

execution, involving multidisciplinary knowledge in electronics, software, and biomedical

applications.

Problem Solving: Enhanced troubleshooting skills by overcoming design challenges such as

signal distortion, power supply limitations, and noise reduction techniques.

Communication and Documentation: Improved technical documentation and presentation

skills by preparing project reports, diagrams, and software guides.

ALL THE RESOURCES ARE AVAILABLE IN THIS GITHUB (https://github.com/shreenandansonu/Electronic-Stethescope) PAGE.

https://github.com/shreenandansonu/Electronic-Stethescope

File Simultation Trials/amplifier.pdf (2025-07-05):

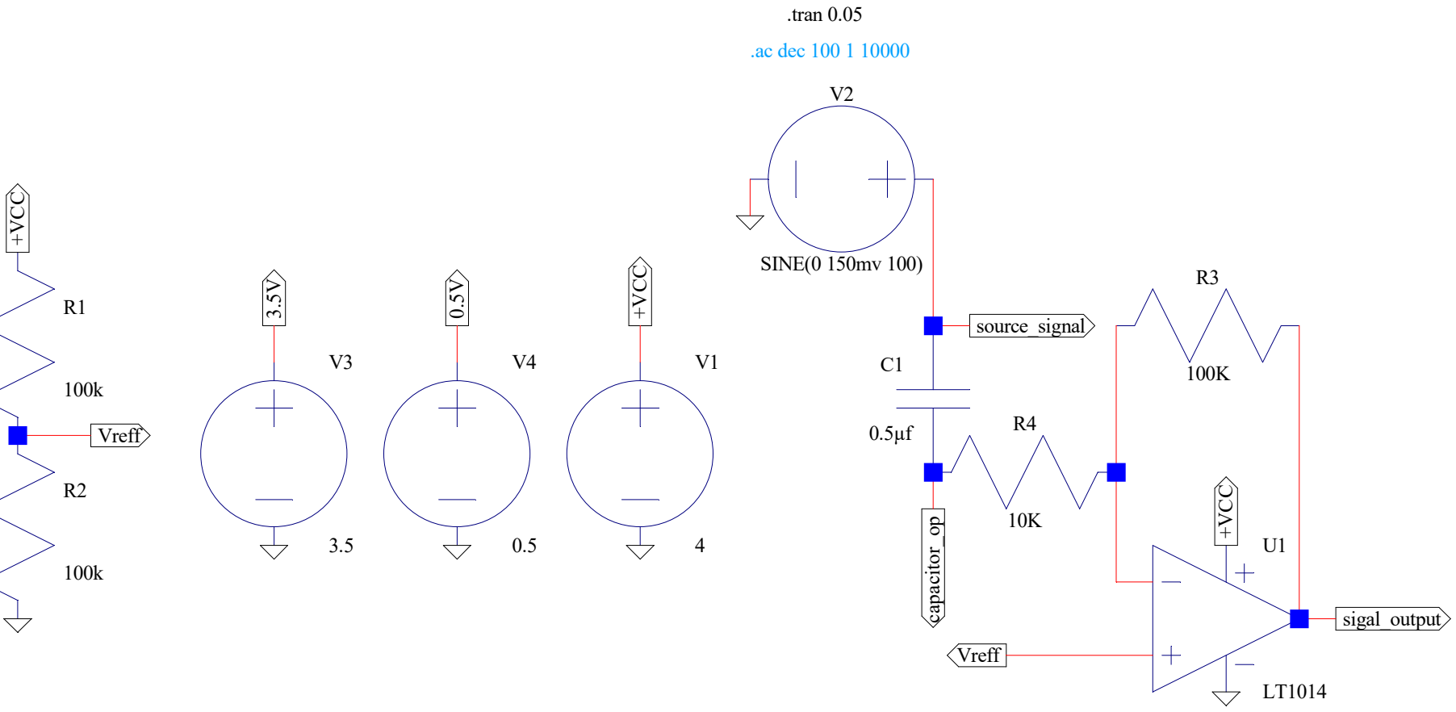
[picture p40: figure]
SINE(0 150mv 100); sigal_output ⁺VCC ⁺VCC; +VCC; Vreff; Vreff capacitor_op; source_signal ³.5V; .tran 0.05; .ac dec 100 1 10000

--- F:\Digital Stethescope\Simultatio\signal_amplifier.asc ---

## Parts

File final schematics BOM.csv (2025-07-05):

Reference | Value | Datasheet | Footprint | Qty | DNP
C1,C2 | 10uF | ~ | Capacitor_THT:CP_Radial_D5.0mm_P2.50mm | 2
C3,C4,C8,C9,C10 | 220pF | ~ | Capacitor_THT:C_Disc_D3.0mm_W2.0mm_P2.50mm | 5
C5,C6,C7,C12 | 100nF | ~ | Capacitor_THT:C_Disc_D3.0mm_W2.0mm_P2.50mm | 4
C11 | 47uF | ~ | Capacitor_THT:CP_Radial_D5.0mm_P2.50mm | 1
C13,C14,C16,C17,C18 | 82pF | ~ | Capacitor_THT:C_Disc_D3.0mm_W2.0mm_P2.50mm | 5
C15 | 47nF | ~ | Capacitor_THT:C_Disc_D3.0mm_W2.0mm_P2.50mm | 1
D1 | LED | ~ | LED_THT:LED_D3.0mm_Clear | 1
J1 | HeadPhone | ~ | Connector_Audio:Jack_3.5mm_Ledino_KB3SPRS_Horizontal | 1
J2 | Stethescope Out | ~ |  | 1
J3 | AFE In | ~ | Connector_Audio:Jack_3.5mm_Ledino_KB3SPRS_Horizontal | 1
J4 | Record | ~ | Connector_Audio:Jack_3.5mm_Ledino_KB3SPRS_Horizontal | 1
J5 | PWR | ~ | Connector_JST:JST_EH_B2B-EH-A_1x02_P2.50mm_Vertical | 1
J6 | Switch | ~ | Connector_JST:JST_EH_B2B-EH-A_1x02_P2.50mm_Vertical | 1
J7 | POT con | ~ | Connector_PinHeader_2.54mm:PinHeader_1x03_P2.54mm_Vertical | 1
MK1 | Prim MIC | ~ |  | 1
MK2 | Sec MIC | ~ |  | 1
R1,R3,R8,R9 | 10K | ~ | Resistor_THT:R_Axial_DIN0207_L6.3mm_D2.5mm_P7.62mm_Horizontal | 4
R2,R6,R24 | 1K | ~ | Resistor_THT:R_Axial_DIN0207_L6.3mm_D2.5mm_P7.62mm_Horizontal | 3
R4,R5,R10,R16 | 100K | ~ | Resistor_THT:R_Axial_DIN0207_L6.3mm_D2.5mm_P7.62mm_Horizontal | 4
R7 | 100 | ~ | Resistor_THT:R_Axial_DIN0207_L6.3mm_D2.5mm_P7.62mm_Horizontal | 1
R11,R12,R13,R14,R17,R18,R19,R20,R21,R23 | 1M | ~ | Resistor_THT:R_Axial_DIN0207_L6.3mm_D2.5mm_P7.62mm_Horizontal | 10
R15,R22 | 47K | ~ | Resistor_THT:R_Axial_DIN0207_L6.3mm_D2.5mm_P7.62mm_Horizontal | 2
SW1 | Op Mode | ~ | Button_Switch_THT:SW_Slide_SPDT_Angled_CK_OS102011MA1Q | 1
U1 | INA128 | http://www.ti.com/lit/ds/symlink/ina128.pdf | Package_DIP:DIP-8_W7.62mm | 1
U2,U3 | NE5532 | http://www.ti.com/lit/ds/symlink/ne5532.pdf | Package_DIP:DIP-8_W7.62mm | 2
U4 | TL074 | http://www.ti.com/lit/ds/symlink/tl071.pdf | Package_DIP:DIP-14_W7.62mm | 1

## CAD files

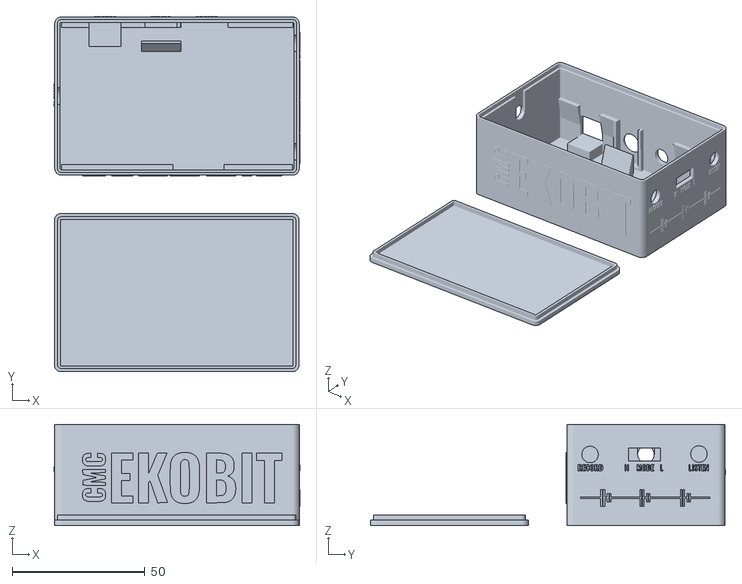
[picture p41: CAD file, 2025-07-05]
3D Design/Print STL/enclouserekobit.stl
92.5 x 133.7 x 38.0

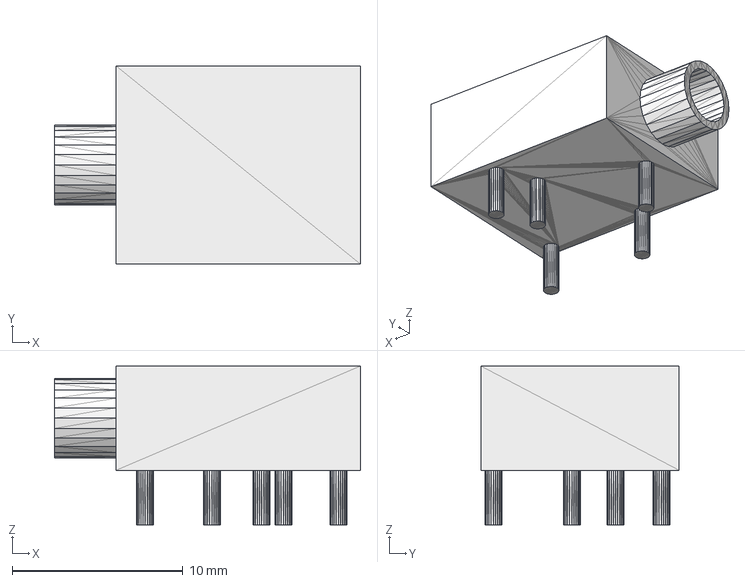
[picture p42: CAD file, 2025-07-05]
Schematics and PCB design/THT version/final schematics/3.5.stp
17.9 x 11.6 x 9.30 mm

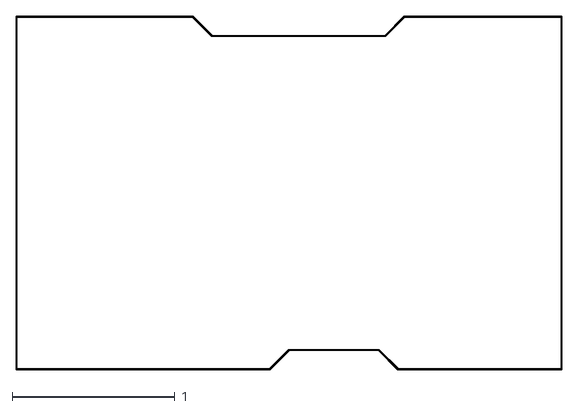
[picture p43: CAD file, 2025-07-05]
Schematics and PCB design/THT version/final schematics/enclouser/final schematics-Edge_Cuts.dxf
3.35 x 2.17

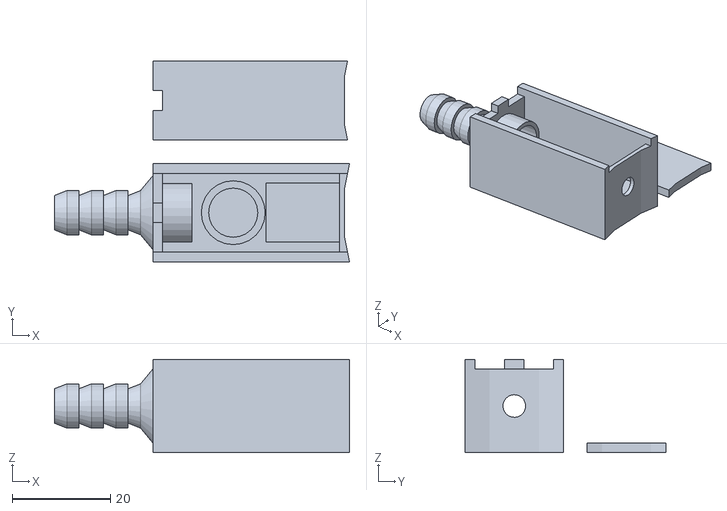
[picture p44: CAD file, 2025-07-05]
3D Design/Print STL/Mic Holder.stl
60.0 x 40.8 x 19.0

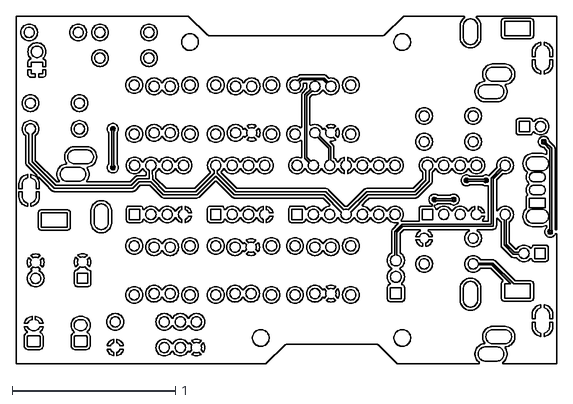
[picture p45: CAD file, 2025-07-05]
Schematics and PCB design/THT version/final schematics/enclouser/final schematics-B_Cu.dxf
3.31 x 2.13

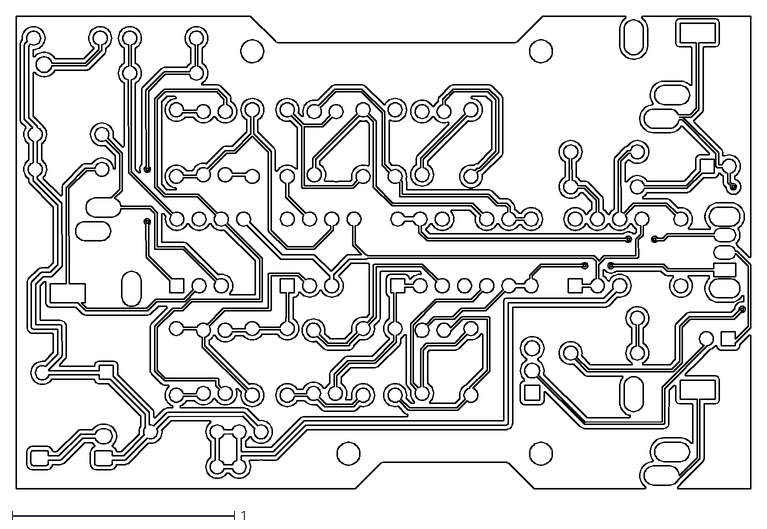
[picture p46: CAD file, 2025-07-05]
Schematics and PCB design/THT version/final schematics/enclouser/final schematics-F_Cu.dxf
3.31 x 2.13

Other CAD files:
3D Design/Mic Holder.skp
3D Design/enclouserekobit.skp
Schematics and PCB design/THT version/final schematics/enclouser/final schematics-B_Mask.dxf
Schematics and PCB design/THT version/final schematics/enclouser/final schematics-B_Paste.dxf
Schematics and PCB design/THT version/final schematics/enclouser/final schematics-B_Silkscreen.dxf
Schematics and PCB design/THT version/final schematics/enclouser/final schematics-F_Mask.dxf
Schematics and PCB design/THT version/final schematics/enclouser/final schematics-F_Paste.dxf
Schematics and PCB design/THT version/final schematics/enclouser/final schematics-F_Silkscreen.dxf

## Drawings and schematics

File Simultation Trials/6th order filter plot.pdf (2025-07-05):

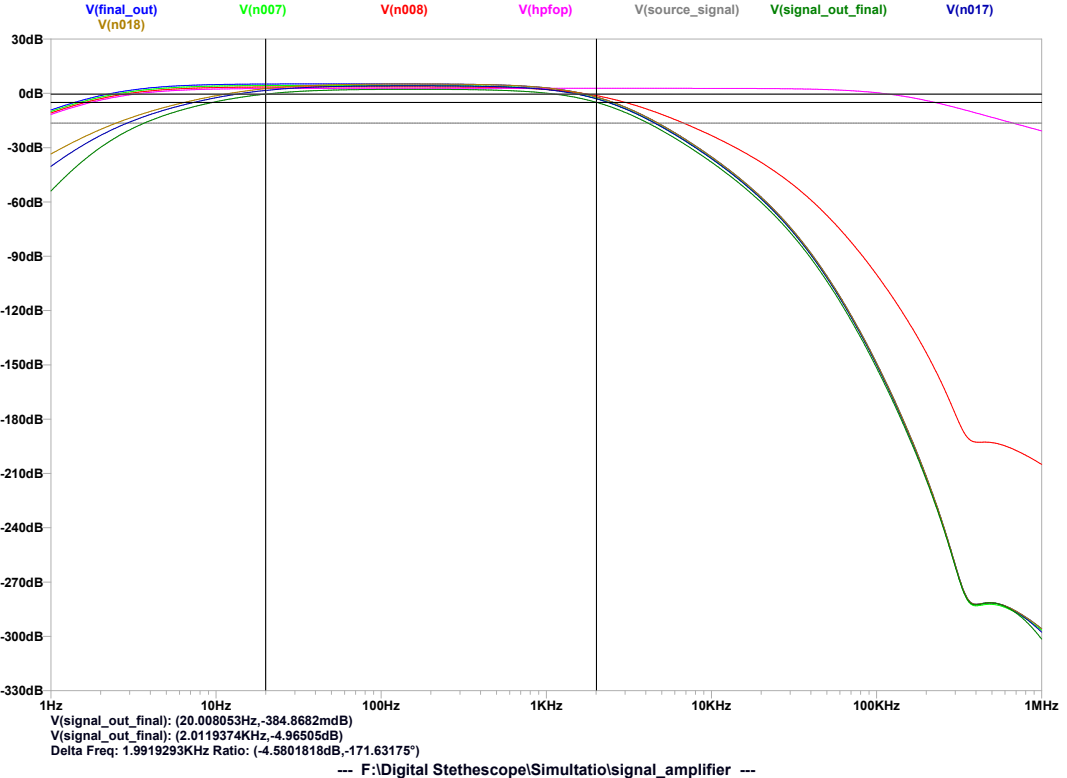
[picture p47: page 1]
1KHz; 10KHz; 100KHz; 1MHz; V(final_out); V(hpfop); V(source_signal); V(signal_out_final); V(signal_out_final): (20.008053Hz,-384.8682mdB) V(signal_out_final): (2.0119374KHz,-4.96505dB) Delta Freq: 1.9919293KHz Ratio: (-4.5801818dB,-171.63175°)

--- F:\Digital Stethescope\Simultatio\signal_amplifier ---

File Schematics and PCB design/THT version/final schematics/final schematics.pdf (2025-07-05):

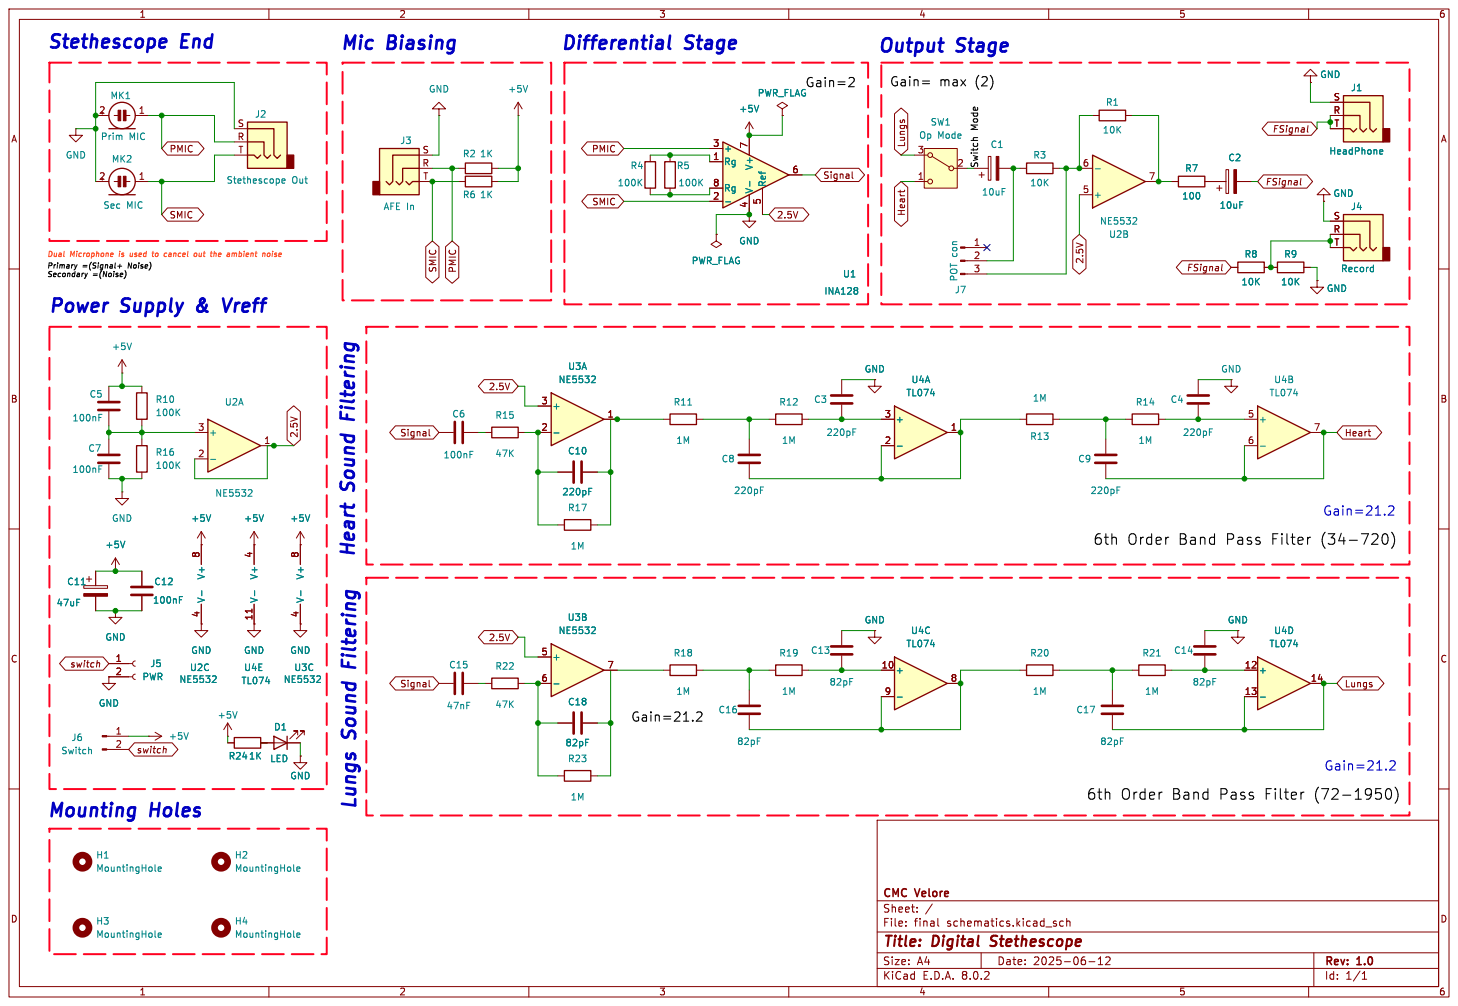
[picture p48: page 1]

Gain=2 Heart Sound Filtering

Dual Microphone is used to cancel out the ambient noise Mounting Holes

6th Order Band Pass Filter (34-720)

File: final schematics.kicad_sch Sheet: / CMC Velore R19

6th Order Band Pass Filter (72-1950)

H2 MountingHole H4 MountingHole H3 MountingHole H1 MountingHole

Id: 1/1 Title: Digital Stethescope

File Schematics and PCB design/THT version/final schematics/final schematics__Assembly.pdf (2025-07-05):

1 | 2 | 3 | 4 | 5 | 6

A

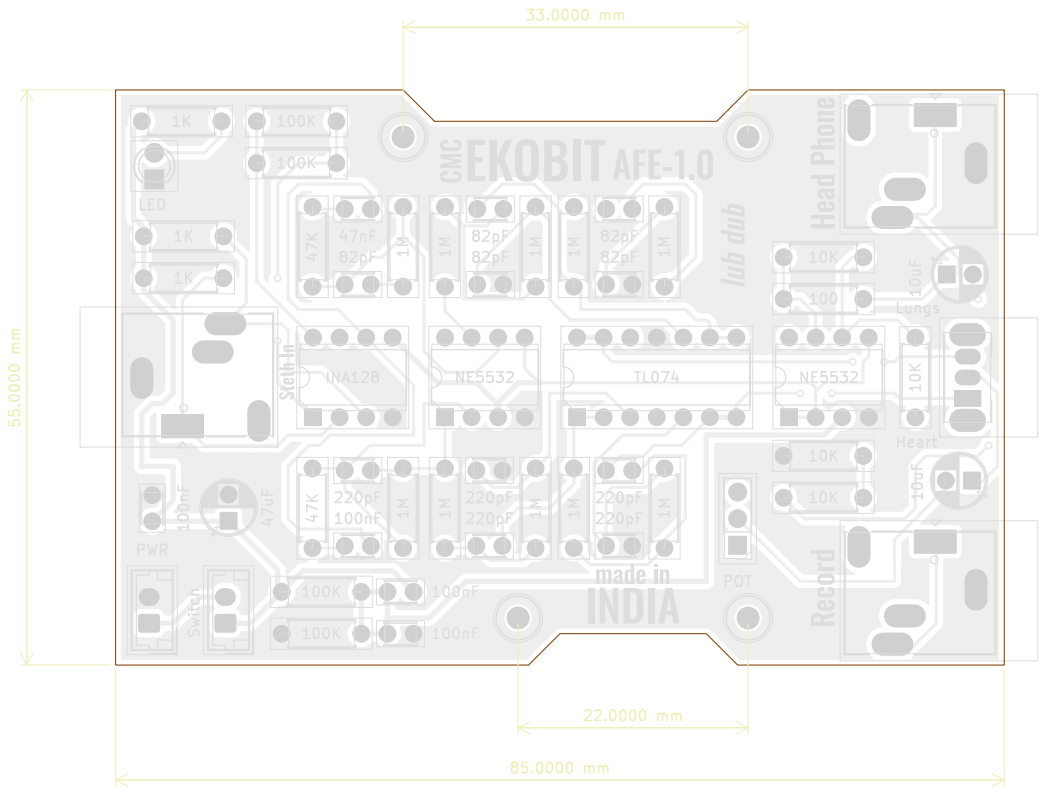
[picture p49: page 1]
EKOBIT; Lungs lubdub; Heart CMC; AFE-1.0; INDIA; madein; 10K Switch; 100K⁴⁷K; POT; HeadPhone 100nF; Record ¹M ¹M; PWR; INA128; 1M StethIn; 10KTL074; LED; D Date: 2025-06-13 KiCad; E.D.A. 8.0.2 Size: A4; Rev: 1.0; File: final schematics.kicad_pcb Sheet: Light Colors; PCB; Fabrication; TOP; Shreenandan Sahu Board2Pdf:; Light Colors PCB Fabrication; TOP - Page 1/3

Id: 1/1 Title: PCB Design of CMC EKOBIT

A

A

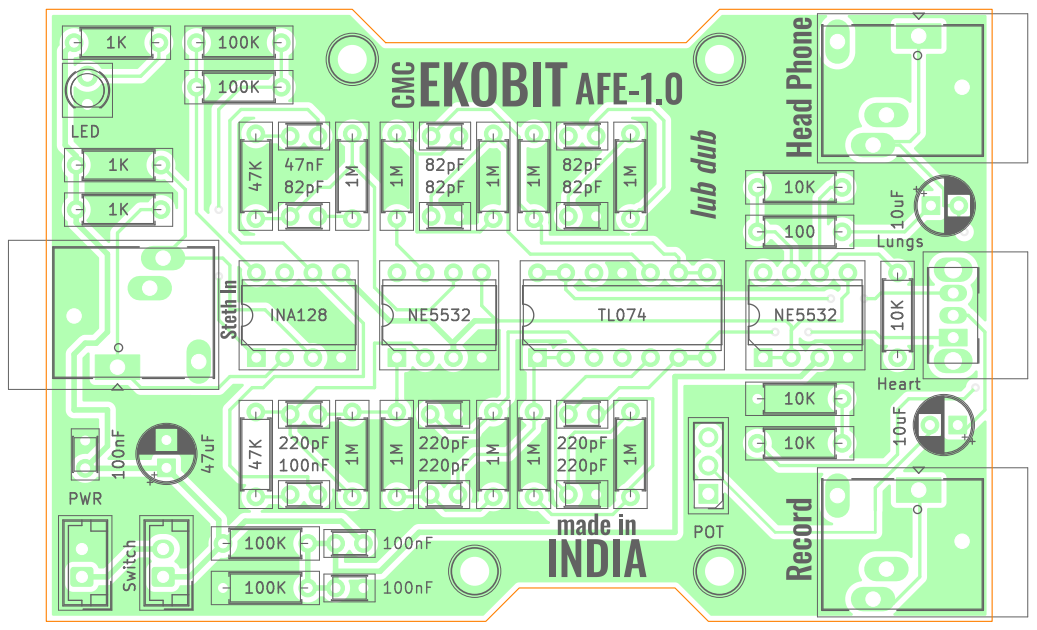
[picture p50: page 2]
EKOBIT; Lungs lubdub; Heart CMC; AFE-1.0; INDIA; madein; 10K Switch; 100K⁴⁷K; POT; HeadPhone 100nF; Record ¹M ¹M; PWR; INA128; 1M StethIn; 10KTL074; LED; D Date: 2025-06-13 KiCad; E.D.A. 8.0.2 Size: A4; Rev: 1.0; File: final schematics.kicad_pcb Sheet: Colored; TOP; Shreenandan Sahu Board2Pdf:; Colored; TOP -; Page 2/3

Id: 1/1 Title: PCB Design of CMC EKOBIT

A

A

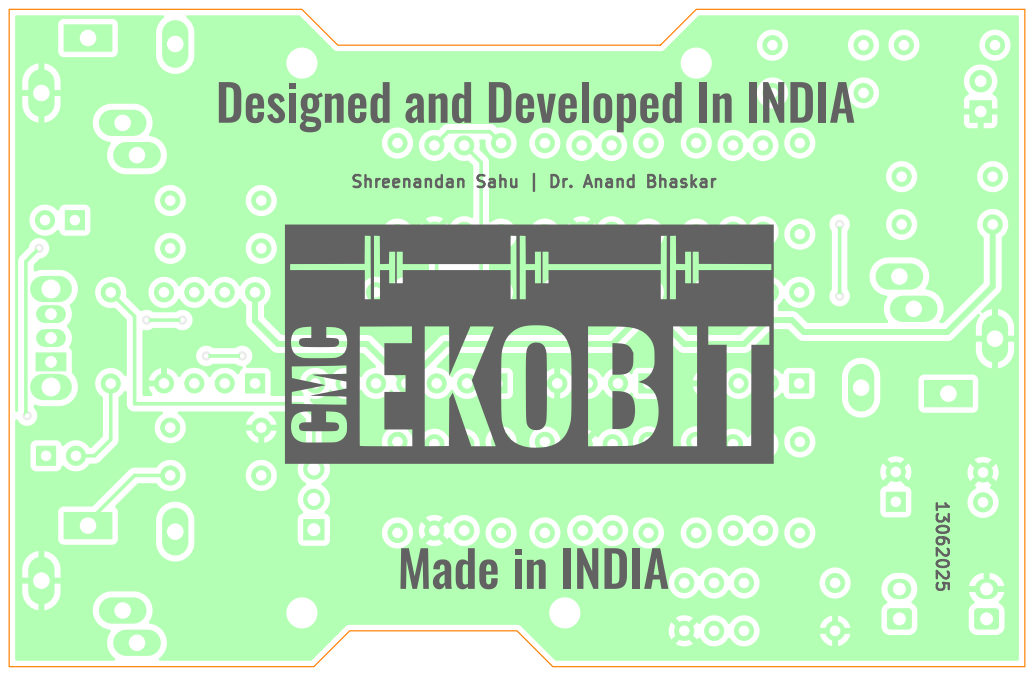
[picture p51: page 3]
MadeinINDIA; DesignedandDevelopedInINDIA 13062025 Shreenandan; Sahu; | Dr. Anand Bhaskar; D Date: 2025-06-13 KiCad; E.D.A. 8.0.2 Size: A4; Rev: 1.0; File: final schematics.kicad_pcb Sheet: Colored; BOT Shreenandan Sahu Board2Pdf:; Colored; BOT -; Page 3/3

Id: 1/1 Title: PCB Design of CMC EKOBIT

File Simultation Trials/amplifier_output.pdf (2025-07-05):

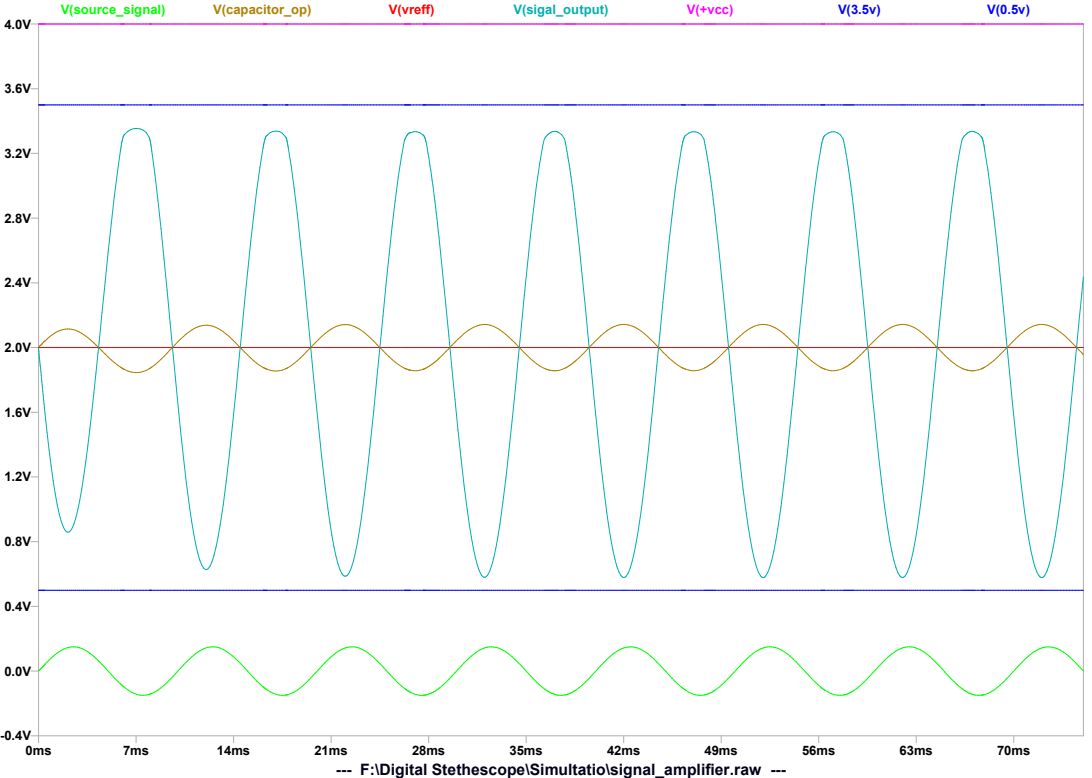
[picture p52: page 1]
V(source_signal); V(capacitor_op); V(vreff); V(sigal_output); V(+vcc)

--- F:\Digital Stethescope\Simultatio\signal_amplifier.raw ---

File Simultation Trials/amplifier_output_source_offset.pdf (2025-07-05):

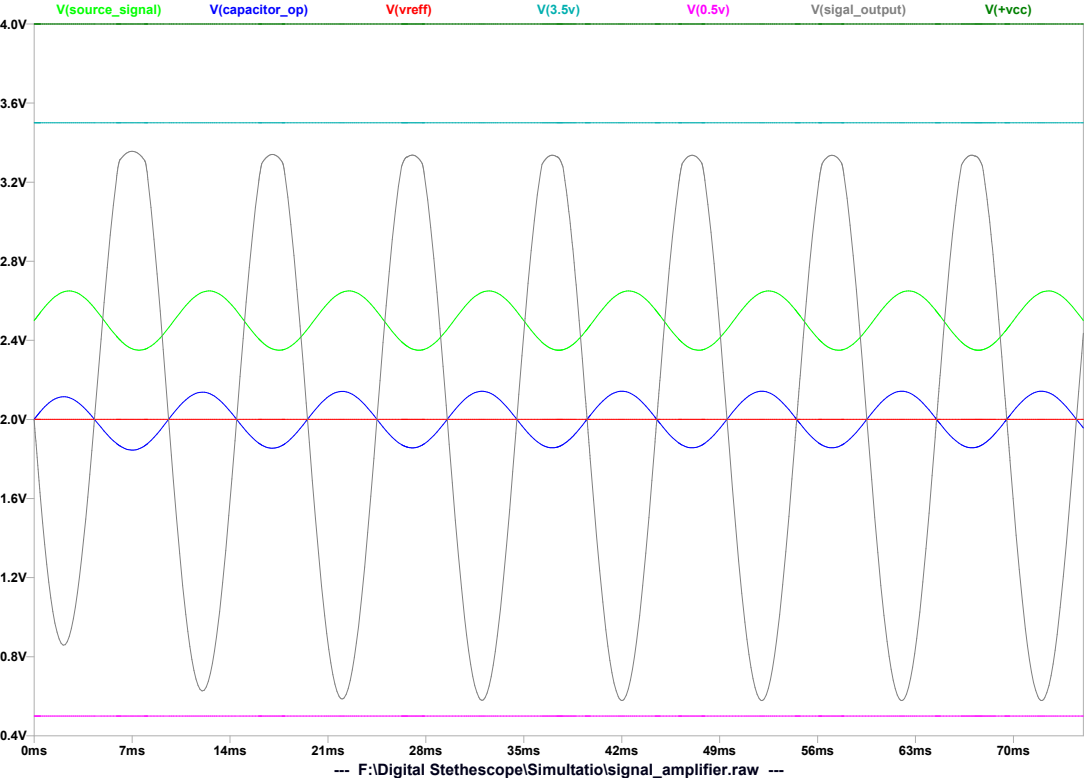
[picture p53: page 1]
V(source_signal); V(capacitor_op); V(vreff); V(sigal_output); V(+vcc)

--- F:\Digital Stethescope\Simultatio\signal_amplifier.raw ---

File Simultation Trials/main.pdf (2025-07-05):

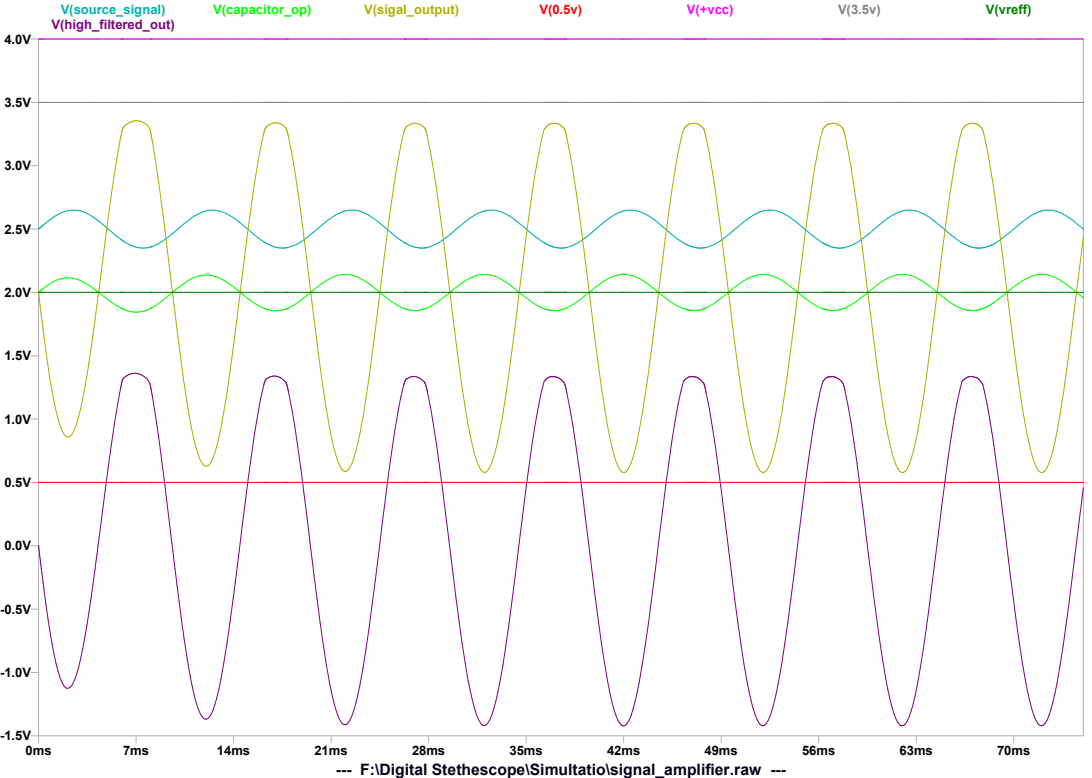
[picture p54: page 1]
V(source_signal); V(capacitor_op); V(sigal_output); V(+vcc); V(vreff); V(high_filtered_out)

--- F:\Digital Stethescope\Simultatio\signal_amplifier.raw ---

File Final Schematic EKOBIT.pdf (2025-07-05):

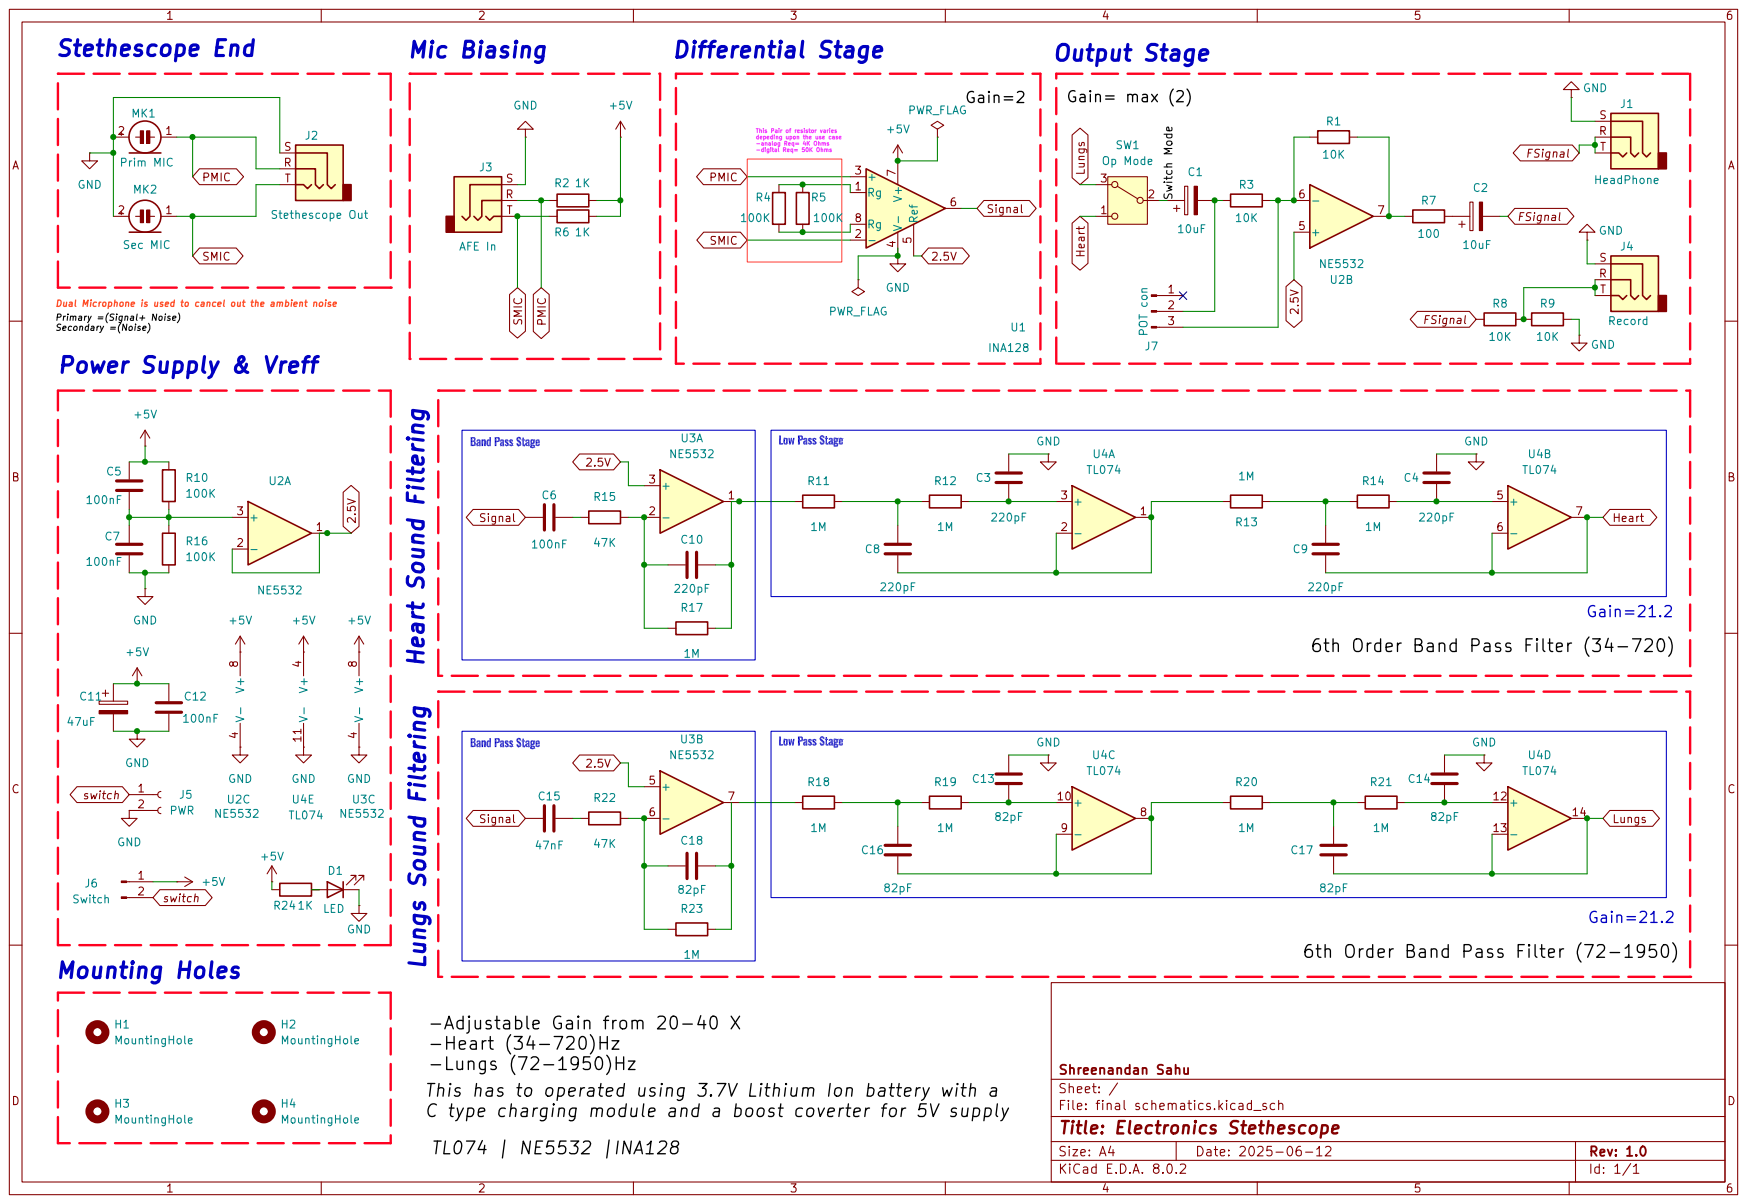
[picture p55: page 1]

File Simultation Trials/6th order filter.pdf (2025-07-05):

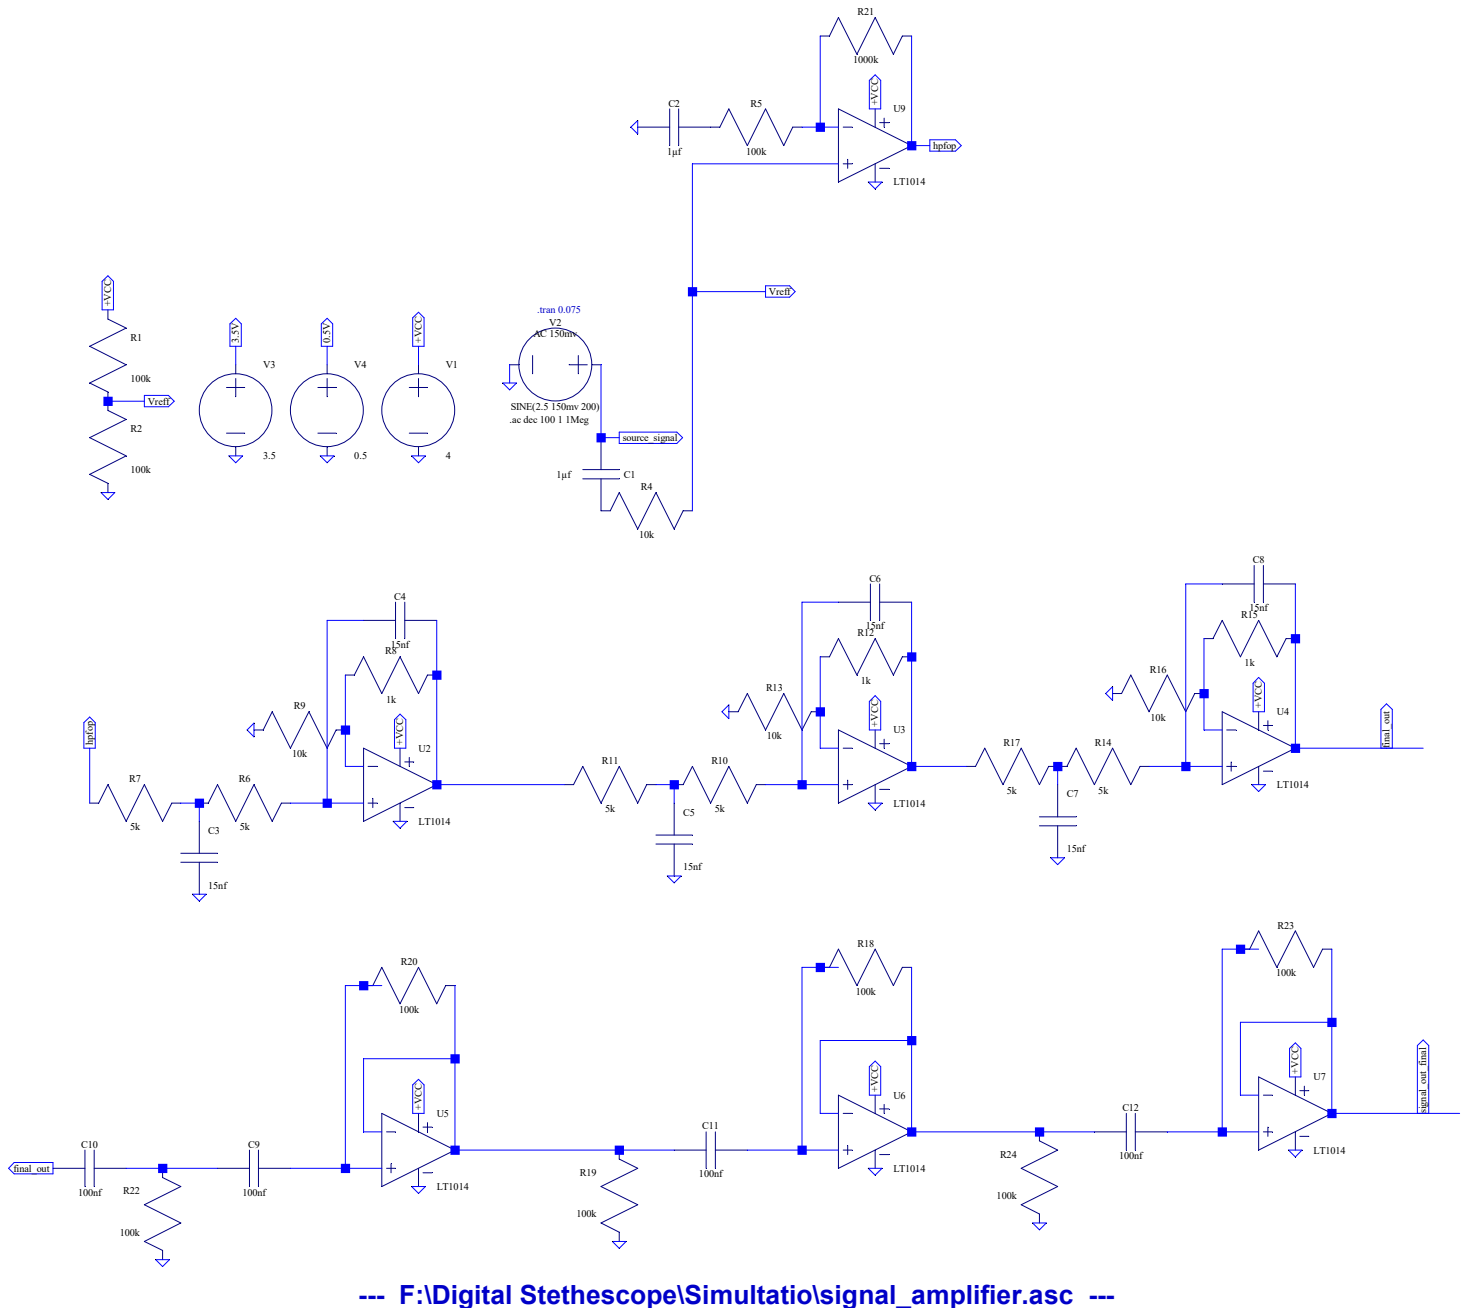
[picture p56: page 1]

--- F:\Digital Stethescope\Simultatio\signal_amplifier.asc ---

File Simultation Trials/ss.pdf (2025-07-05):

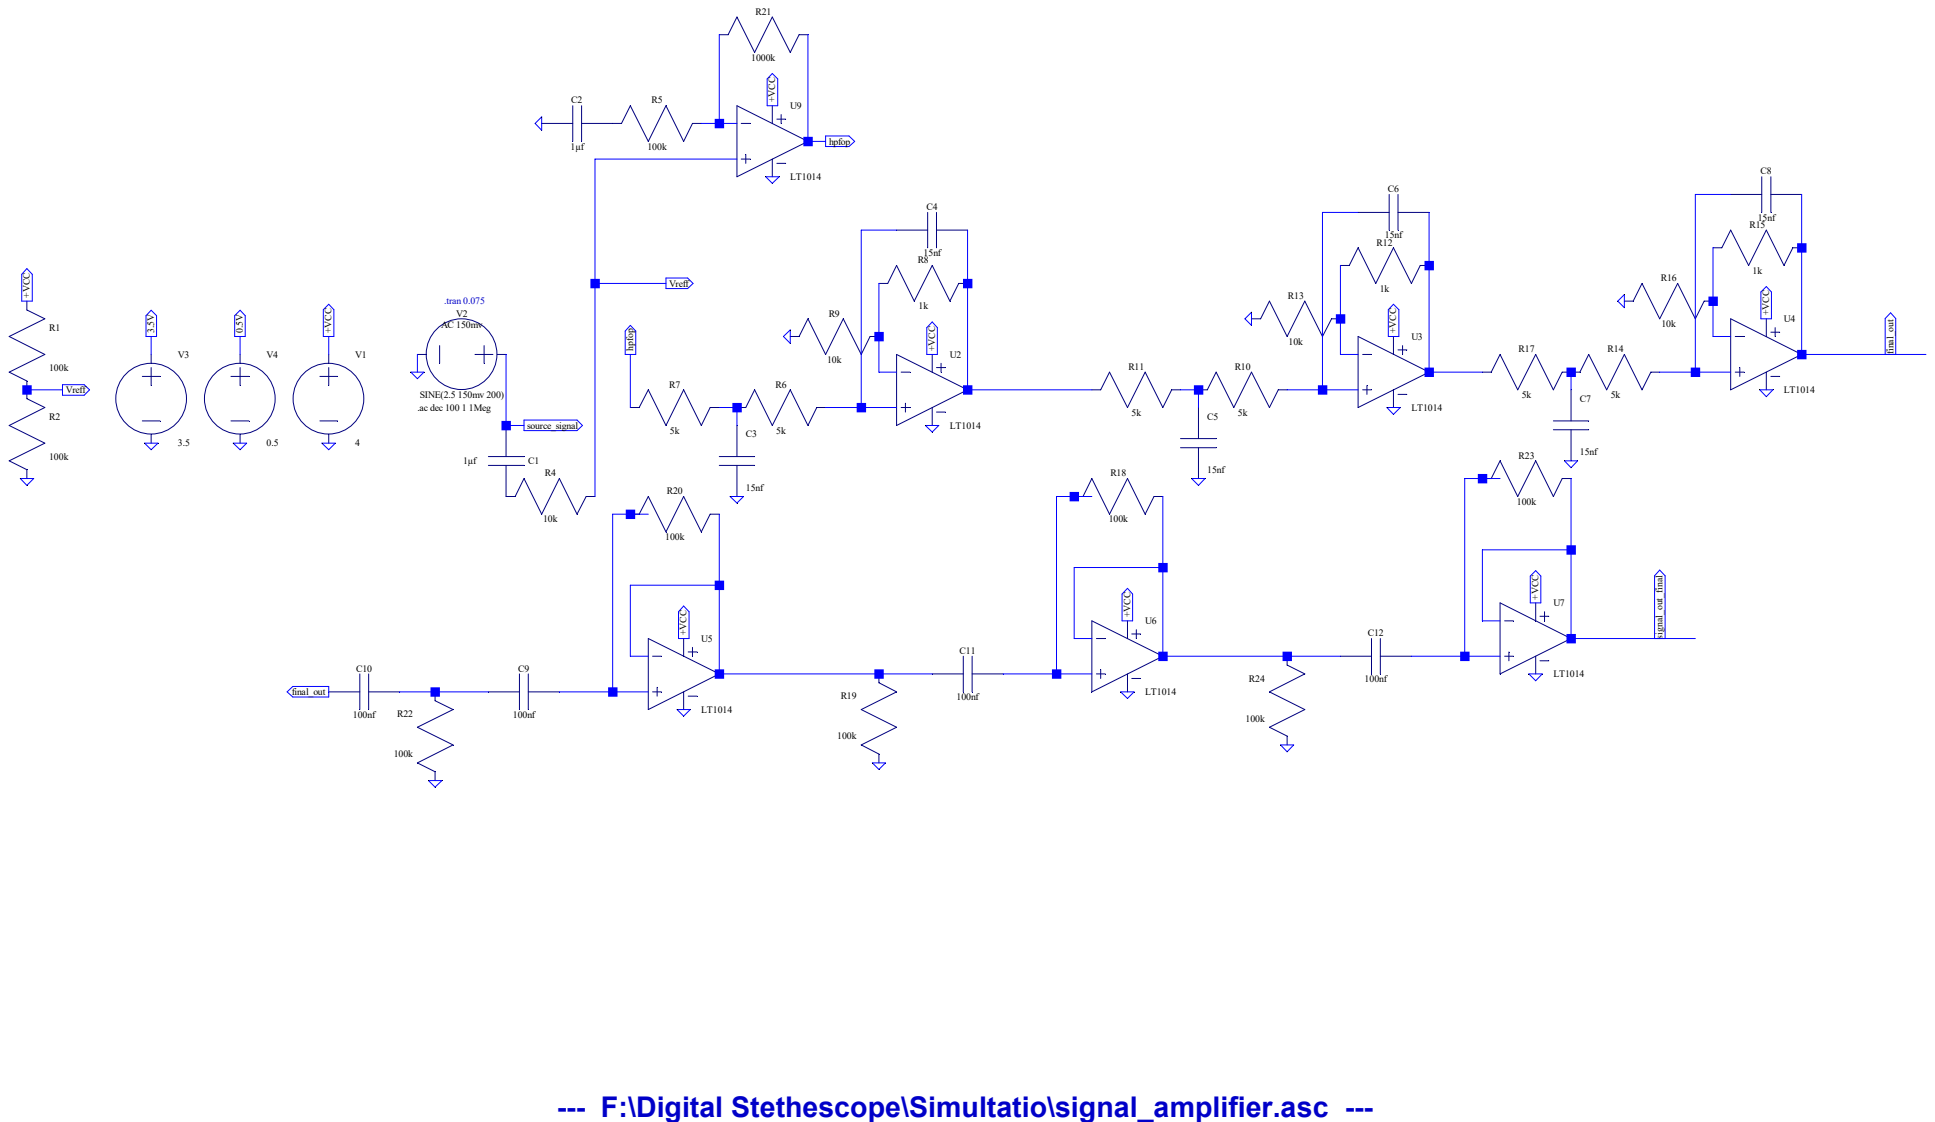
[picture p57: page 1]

--- F:\Digital Stethescope\Simultatio\signal_amplifier.asc ---

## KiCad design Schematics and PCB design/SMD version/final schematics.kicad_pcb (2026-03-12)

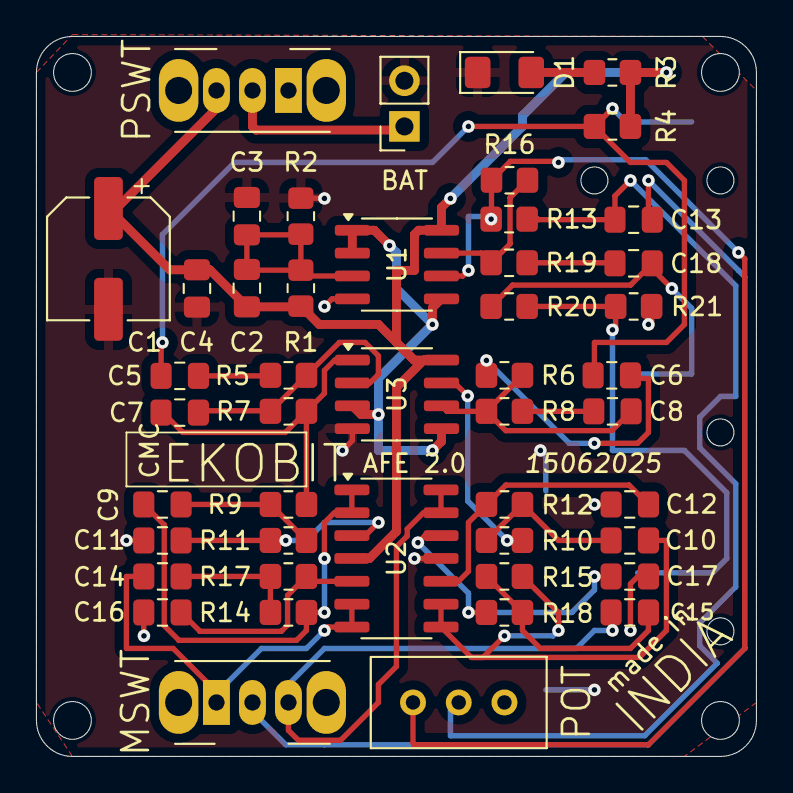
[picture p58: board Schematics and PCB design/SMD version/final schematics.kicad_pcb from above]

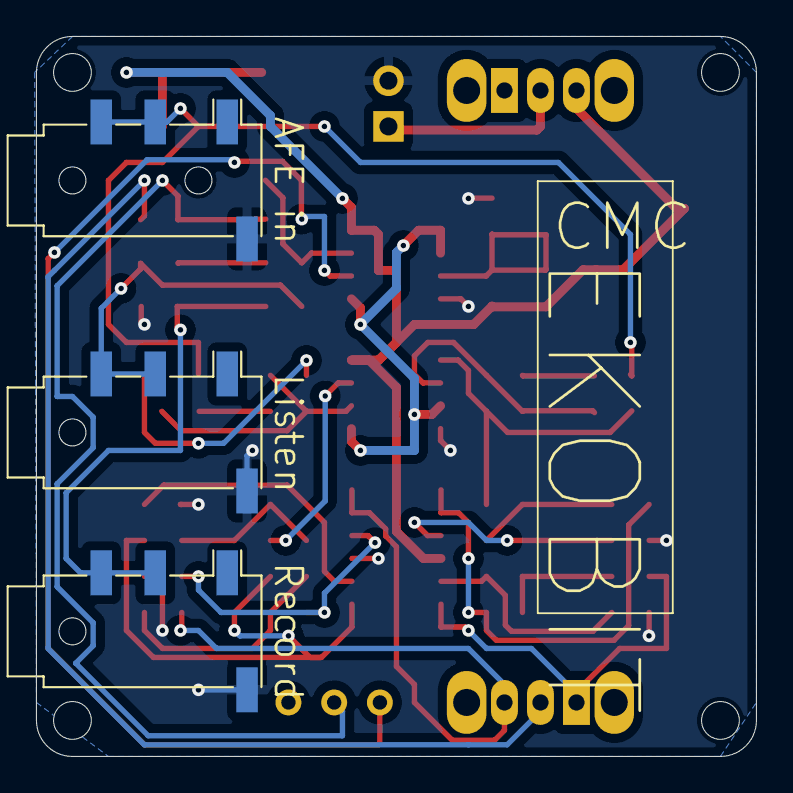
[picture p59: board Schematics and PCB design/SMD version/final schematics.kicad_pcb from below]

Board: 2 copper layers, 40.0 x 40.0 mm, 54 parts (3 on the bottom side), 33 nets.

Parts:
AFE in: AFE In; Jack_3.5mm_PJ320D_Horizontal
BAT: PWR; PinSocket_1x02_P2.54mm_Vertical
C1: 47uF; CP_Elec_6.3x5.4
C2, C3, C4, C5: 100nF; C_0805_2012Metric_Pad1.18x1.45mm_HandSolder
C6: 47nF; C_0805_2012Metric_Pad1.18x1.45mm_HandSolder
C7, C9, C11, C14, C16: 220pF; C_0805_2012Metric_Pad1.18x1.45mm_HandSolder
C8, C10, C12, C15, C17: 82pF; C_0805_2012Metric_Pad1.18x1.45mm_HandSolder
C13, C18: 10uF; C_0805_2012Metric_Pad1.18x1.45mm_HandSolder
D1: LED; LED_1206_3216Metric_Pad1.42x1.75mm_HandSolder
H1, H2, H3, H4: MountingHole; MountingHole_2.1mm
Listen: HeadPhone; Jack_3.5mm_PJ320D_Horizontal
MSWT: Op Mode; SW_Slide_SPDT_Angled_CK_OS102011MA1Q
POT: 10K pot; Potentiometer_Bourns_3296W_Vertical
PSWT: PSWT; SW_Slide_SPDT_Angled_CK_OS102011MA1Q
R1, R2: 100K; R_0805_2012Metric_Pad1.20x1.40mm_HandSolder
R3, R4: 1K; R_0805_2012Metric_Pad1.20x1.40mm_HandSolder
R5, R6: 47K; R_0805_2012Metric_Pad1.20x1.40mm_HandSolder
R7, R8, R9, R10, R11, R12, R14, R15, R17, R18: 1M; R_0805_2012Metric_Pad1.20x1.40mm_HandSolder
R13, R16: 20K; R_0805_2012Metric_Pad1.20x1.40mm_HandSolder
R19: 100; R_0805_2012Metric_Pad1.20x1.40mm_HandSolder
R20, R21: 10K; R_0805_2012Metric_Pad1.20x1.40mm_HandSolder
Record: Record; Jack_3.5mm_PJ320D_Horizontal
U1, U3: NE5532; SOIC-8_3.9x4.9mm_P1.27mm
U2: TL074; SOIC-14_3.9x8.7mm_P1.27mm

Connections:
2.5V: U1.1, U1.2 (-), U1.5 (+), U3.3 (+), U3.5 (+)
+5V: C1.1, C2.1, C4.1, PSWT.3 (A), R1.1, R3.1, R4.2, U1.8 (V+), U2.4 (V+), U3.8 (V+)
FSignal: C18.2, Listen.R1, Listen.R2, R20.1
GND: AFE in.S, BAT.2, C1.2, C3.2, C4.2, C11.2, C12.2, C16.2, C17.2, D1.1 (K), Listen.S, R2.2, R21.2, Record.S, U1.4 (V-), U2.11 (V-), U3.4 (V-)
Heart: C14.1, MSWT.1 (C), U2.6 (-), U2.7
Lungs: C15.1, MSWT.3 (A), U2.13 (-), U2.14
unnamed: C5.2, R5.1
unnamed: C6.2, R6.1
unnamed: C7.2, R7.2, R9.1, U3.1
unnamed: C8.2, R8.2
unnamed: C9.2, R9.2, R11.1
unnamed: C10.2, R10.2, R12.1
unnamed: C13.2, POT.2, R13.1
unnamed: C14.2, R14.1, R17.1
unnamed: C15.2, R15.2, R18.1
unnamed: C18.1, R19.2
unnamed: D1.2 (A), R3.2
unnamed: R20.2, R21.1, Record.R1, Record.R2
unnamed: R10.1, U3.7
unnamed: R16.2, R19.1, U1.7
unnamed: C13.1, MSWT.2 (B)
unnamed: C2.2, C3.1, R1.2, R2.1, U1.3 (+)
unnamed: POT.3, R13.2, R16.1, U1.6 (-)
unnamed: C11.1, R11.2, U2.3 (+)
unnamed: C9.1, R14.2, U2.1, U2.2 (-)
unnamed: C16.1, R17.2, U2.5 (+)
unnamed: C12.1, R12.2, U2.10 (+)
unnamed: C10.1, R15.1, U2.8, U2.9 (-)
unnamed: C17.1, R18.2, U2.12 (+)
unnamed: C7.1, R5.2, R7.1, U3.2 (-)
unnamed: C8.1, R6.2, R8.1, U3.6 (-)
Signal: AFE in.R1, AFE in.R2, C5.1, C6.1, R4.1
switch: BAT.1, PSWT.2 (B)

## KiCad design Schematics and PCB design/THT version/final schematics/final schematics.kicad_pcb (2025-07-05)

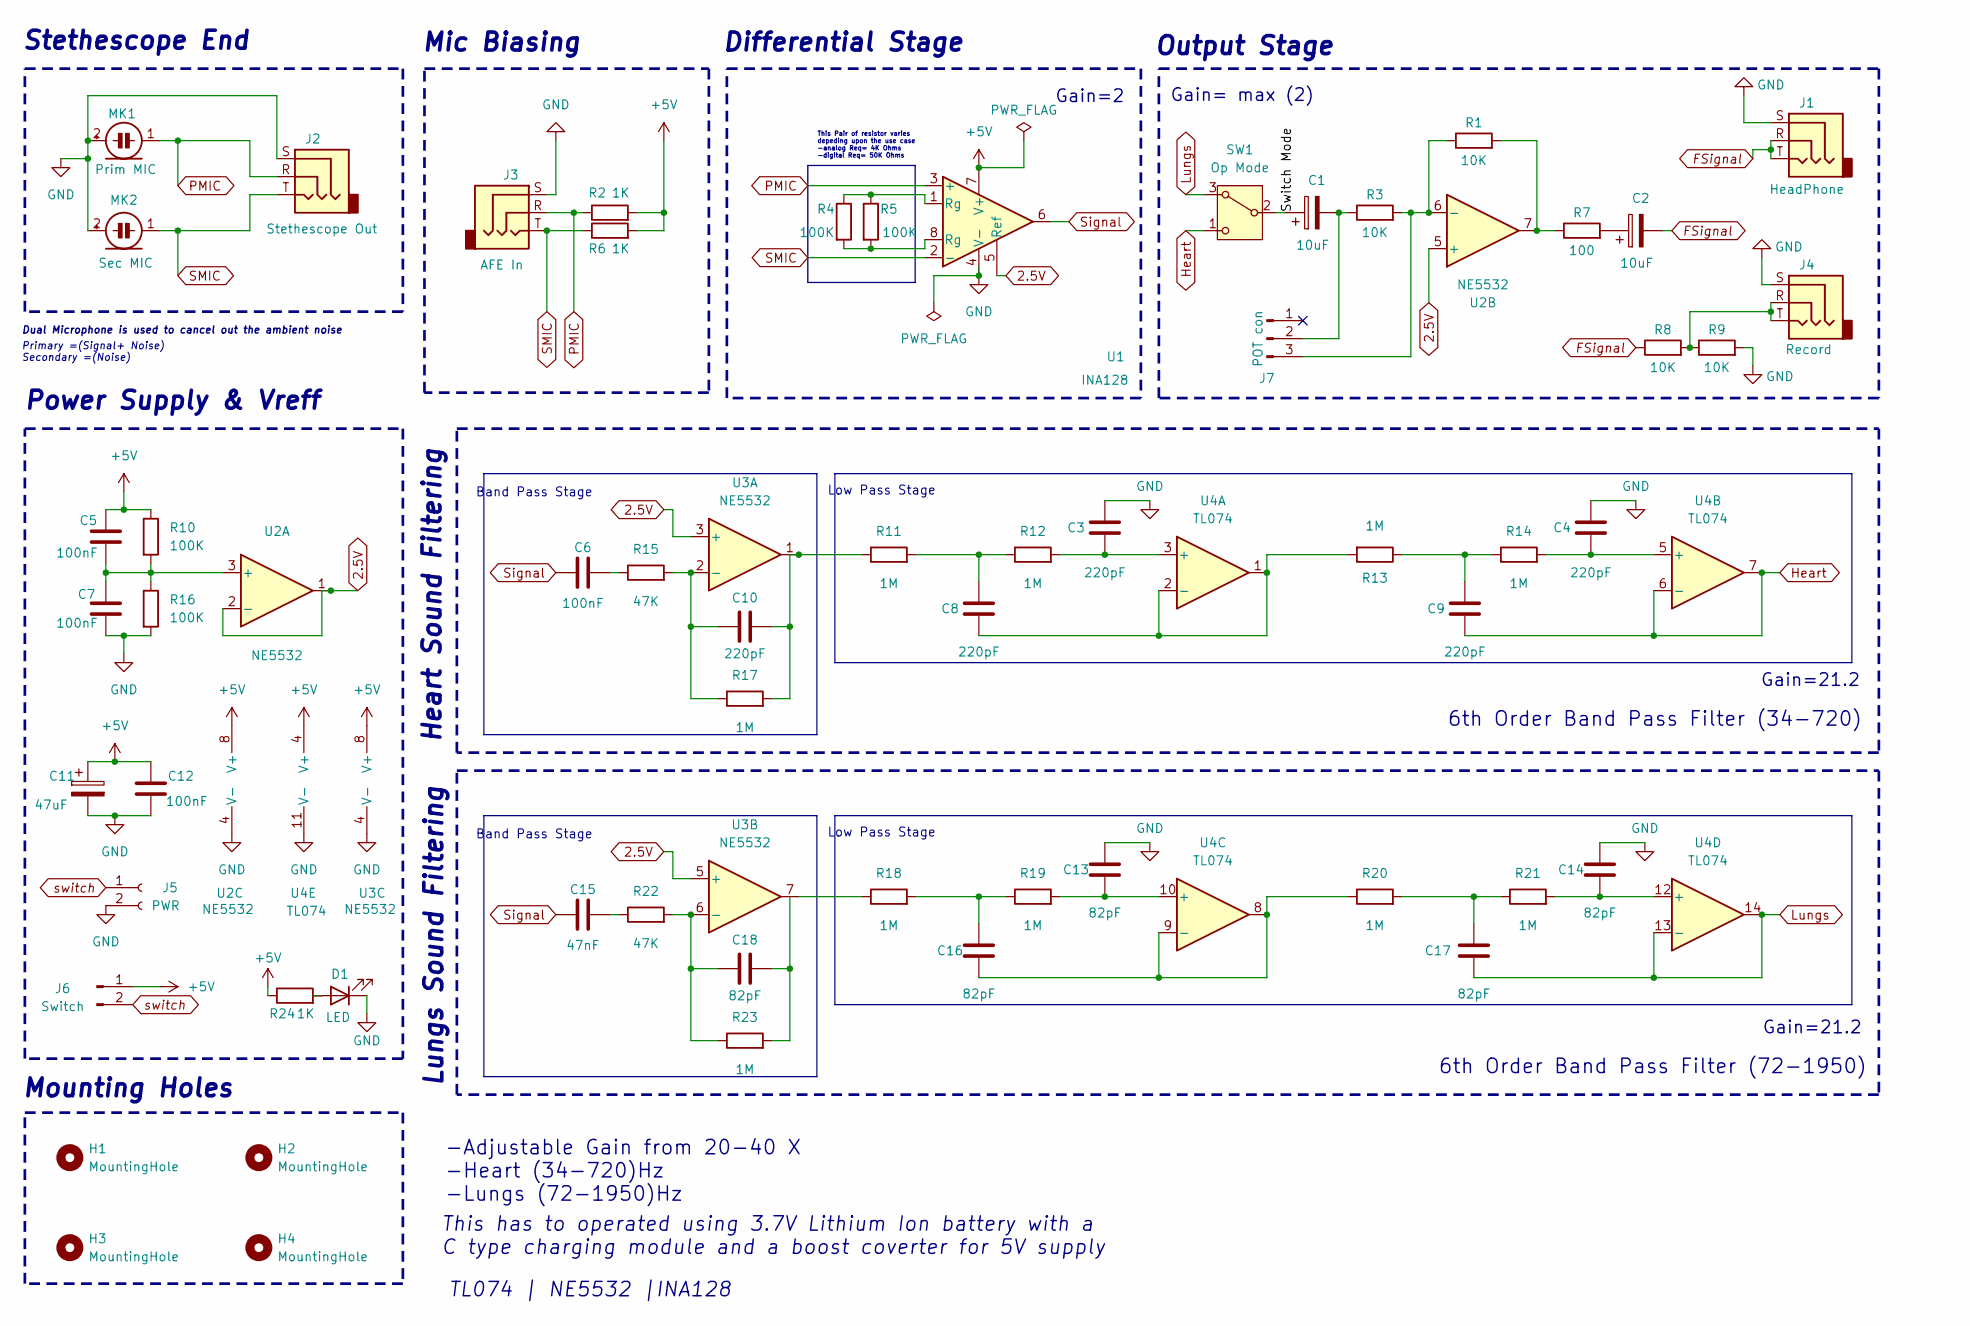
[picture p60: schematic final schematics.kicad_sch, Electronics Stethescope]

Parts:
C1, C2: 10uF; CP_Radial_D5.0mm_P2.50mm
C3, C4, C8, C9, C10: 220pF; C_Disc_D3.0mm_W2.0mm_P2.50mm
C5, C6, C7, C12: 100nF; C_Disc_D3.0mm_W2.0mm_P2.50mm
C11: 47uF; CP_Radial_D5.0mm_P2.50mm
C13, C14, C16, C17, C18: 82pF; C_Disc_D3.0mm_W2.0mm_P2.50mm
C15: 47nF; C_Disc_D3.0mm_W2.0mm_P2.50mm
D1: LED; LED_D3.0mm_Clear
H1, H2, H3, H4: MountingHole; MountingHole_2.1mm
J1: HeadPhone; Jack_3.5mm_Ledino_KB3SPRS_Horizontal
J2: Stethescope Out
J3: AFE In; Jack_3.5mm_Ledino_KB3SPRS_Horizontal
J4: Record; Jack_3.5mm_Ledino_KB3SPRS_Horizontal
J5: PWR; JST_EH_B2B-EH-A_1x02_P2.50mm_Vertical
J6: Switch; JST_EH_B2B-EH-A_1x02_P2.50mm_Vertical
J7: POT con; PinHeader_1x03_P2.54mm_Vertical
MK1: Prim MIC
MK2: Sec MIC
R1, R3, R8, R9: 10K; R_Axial_DIN0207_L6.3mm_D2.5mm_P7.62mm_Horizontal
R2, R6, R24: 1K; R_Axial_DIN0207_L6.3mm_D2.5mm_P7.62mm_Horizontal
R4, R5, R10, R16: 100K; R_Axial_DIN0207_L6.3mm_D2.5mm_P7.62mm_Horizontal
R7: 100; R_Axial_DIN0207_L6.3mm_D2.5mm_P7.62mm_Horizontal
R11, R12, R13, R14, R17, R18, R19, R20, R21, R23: 1M; R_Axial_DIN0207_L6.3mm_D2.5mm_P7.62mm_Horizontal
R15, R22: 47K; R_Axial_DIN0207_L6.3mm_D2.5mm_P7.62mm_Horizontal
SW1: Op Mode; SW_Slide_SPDT_Angled_CK_OS102011MA1Q
U1: INA128; DIP-8_W7.62mm
U2, U3: NE5532; DIP-8_W7.62mm
U4: TL074; DIP-14_W7.62mm

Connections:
2.5V: U1.5 (Ref), U2.1, U2.2 (-), U2.5 (+), U3.3 (+), U3.5 (+)
+5V: C5.1, C11.1, C12.1, J6.1, R2.2, R6.2, R10.1, R24.1, U1.7 (V+), U2.8 (V+), U3.8 (V+), U4.4 (V+)
FSignal: C2.2, J1.R, J1.T, R8.1
GND: C3.2, C4.2, C7.2, C11.2, C12.2, C13.2, C14.2, D1.1 (K), J1.S, J2.S, J3.S, J4.S, J5.2, MK1.2 (+), MK2.2 (+), R9.2, R16.2, U1.4 (V-), U2.4 (V-), U3.4 (V-), U4.11 (V-)
Heart: C9.1, SW1.1 (C), U4.6 (-), U4.7
Lungs: C17.1, SW1.3 (A), U4.13 (-), U4.14
unnamed: C2.1, R7.2
unnamed: C6.2, R15.1
unnamed: C8.2, R11.2, R12.1
unnamed: C9.2, R13.1, R14.1
unnamed: C10.2, R11.1, R17.2, U3.1
unnamed: C15.2, R22.1
unnamed: C16.2, R18.2, R19.1
unnamed: C17.2, R20.2, R21.1
unnamed: C18.2, R23.2
unnamed: D1.2 (A), R24.2
unnamed: J4.R, J4.T, R8.2, R9.1
unnamed: C1.2, J7.2, R3.1
unnamed: J7.3, R1.1, R3.2, U2.6 (-)
unnamed: R1.2, R7.1, U2.7
unnamed: R4.1, R5.1, U1.1 (Rg)
unnamed: R4.2, R5.2, U1.8 (Rg)
unnamed: R18.1, U3.7
unnamed: C1.1, SW1.2 (B)
unnamed: C5.2, C7.1, R10.2, R16.1, U2.3 (+)
unnamed: C10.1, R15.2, R17.1, U3.2 (-)
unnamed: C18.1, R22.2, R23.1, U3.6 (-)
unnamed: C3.1, R12.2, U4.3 (+)
unnamed: C8.1, R13.2, U4.1, U4.2 (-)
unnamed: C4.1, R14.2, U4.5 (+)
unnamed: C13.1, R19.2, U4.10 (+)
unnamed: C16.1, R20.1, U4.8, U4.9 (-)
unnamed: C14.1, R21.2, U4.12 (+)
PMIC: J2.R, J3.R, MK1.1 (-), R2.1, U1.3 (+)
SMIC: J2.T, J3.T, MK2.1 (-), R6.1, U1.2 (-)
Signal: C6.1, C15.1, U1.6
switch: J5.1, J6.2

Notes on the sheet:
Heart Sound Filtering
Gain=2
Low Pass Stage
This has to operated using 3.7V Lithium Ion battery with a C type charging module and a boost coverter for 5V supply
Gain= max (2)
Mounting Holes
Differential Stage
Gain=21.2
6th Order Band Pass Filter (72-1950)
Primary =(Signal+ Noise) Secondary =(Noise)
This Pair of resistor varies depeding upon the use case -analog Req= 4K Ohms -digital Req= 50K Ohms
6th Order Band Pass Filter (34-720)
Output Stage
Lungs Sound Filtering
Stethescope End
Band Pass Stage
Power Supply & Vreff
-Adjustable Gain from 20-40 X -Heart (34-720)Hz -Lungs (72-1950)Hz
TL074 | NE5532 |INA128
Dual Microphone is used to cancel out the ambient noise
Mic Biasing

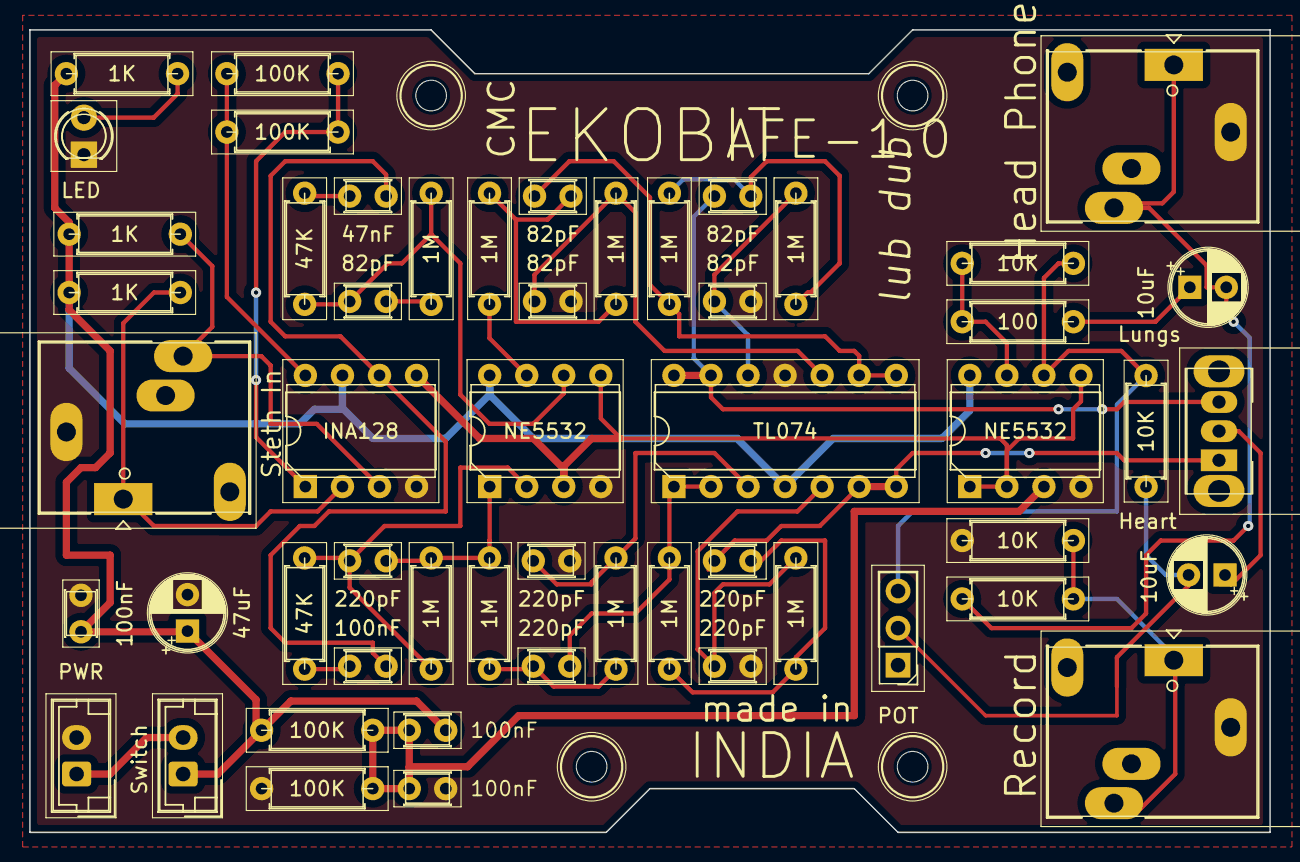
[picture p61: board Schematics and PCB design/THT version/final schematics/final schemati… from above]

Board: 2 copper layers, 85.0 x 55.0 mm, 58 parts (0 on the bottom side), 37 nets.

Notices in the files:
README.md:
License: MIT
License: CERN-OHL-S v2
